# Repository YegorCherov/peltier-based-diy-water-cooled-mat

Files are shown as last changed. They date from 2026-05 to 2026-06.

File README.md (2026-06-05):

# Peltier Water Cooled Sleeping Mat

I bought a water cooled sleeping mat but the station it came with was evaporation based, extremely loud, and needed constant refilling. It also barely worked in hot and humid weather so I decided to build a proper replacement using a peltier module and a real water cooling setup.

It worked but the peltier could not keep up with the heat load so I scrapped it. Everything is documented here anyway because the build itself came out well and the failure is worth understanding.

## Parts

| Part | Details |
|---|---|
| Peltier module | TEC1 12706, 40x40mm, 12V |
| Water block | ARSYLID pure copper, 40x40x10mm |
| Pump | 280L/H brushless DC, 12V 5W, submersible |
| Power supply | 100W 12V switching PSU |
| Motor driver | BTS7960 43A H bridge |
| Buck converter | LM2596 or MP1584, 12V to 5V |
| Microcontroller | ESP32 |
| Coolant | 85% distilled water, 15% car coolant |
| Enclosure | 3D printed |

## Build

The core of the system is the peltier module sandwiched between a copper water block on the cold side and a heatsink with fan on the hot side.

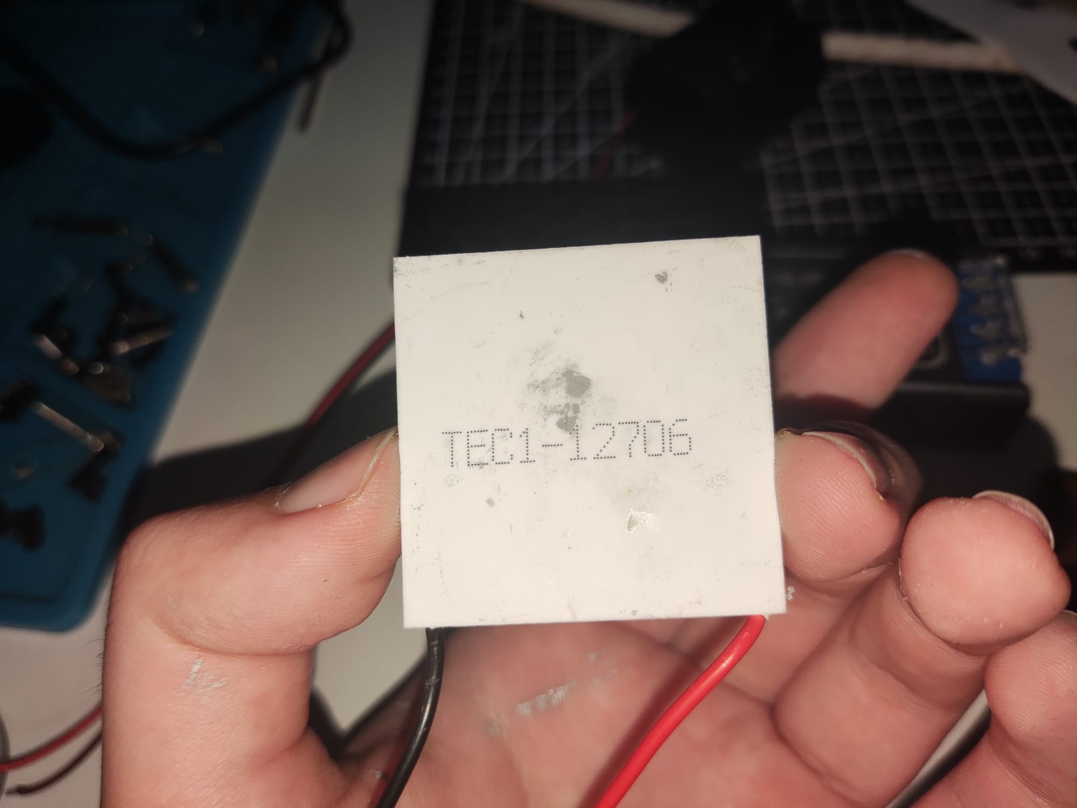
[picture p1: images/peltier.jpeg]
Peltier module


The water block sits against the cold face of the peltier and circulates coolant through the mat.

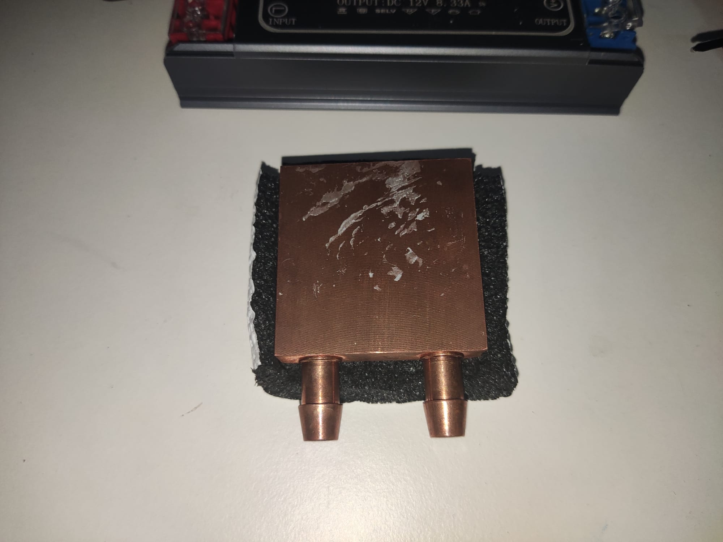
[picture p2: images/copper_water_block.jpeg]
Copper water block


The heatsink and fan go on the hot side to dump heat out of the peltier.

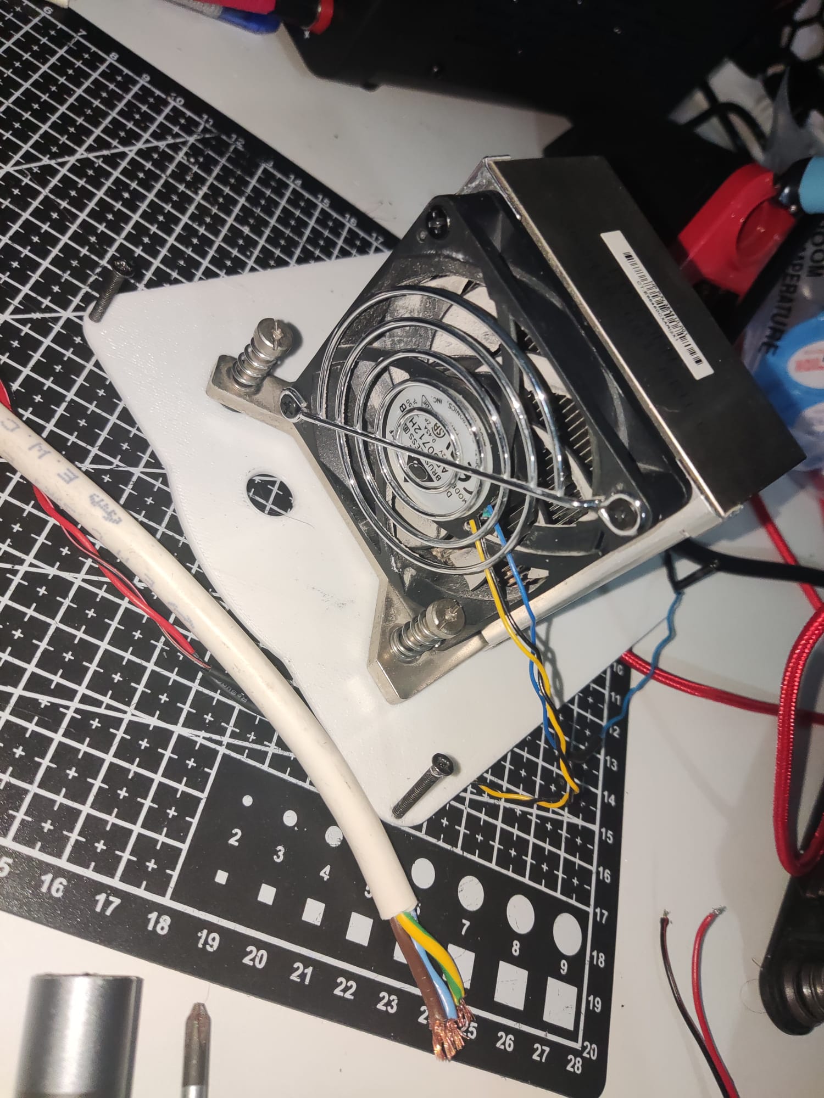
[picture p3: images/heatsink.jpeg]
Heatsink and fan


A brushless submersible pump circulates the coolant through the loop.

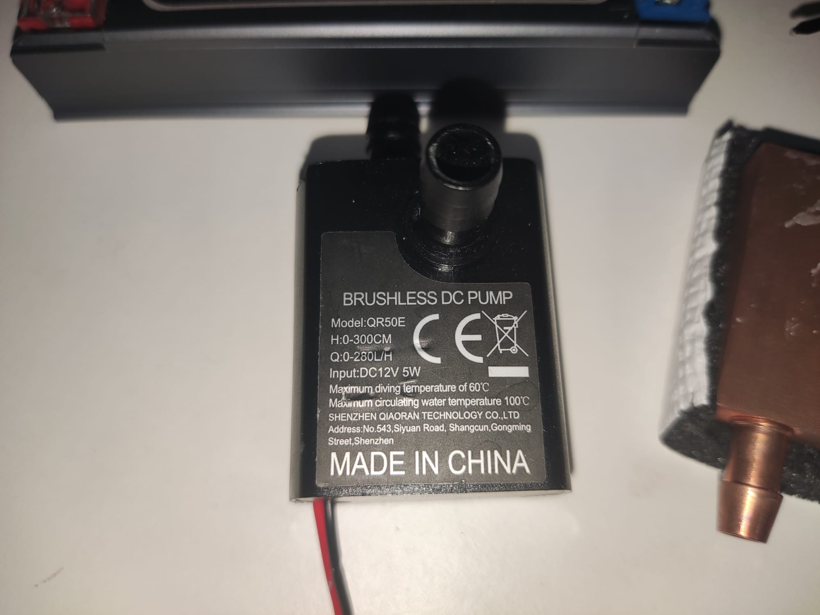
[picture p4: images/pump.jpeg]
Pump


The whole system runs off a 100W 12V switching PSU.

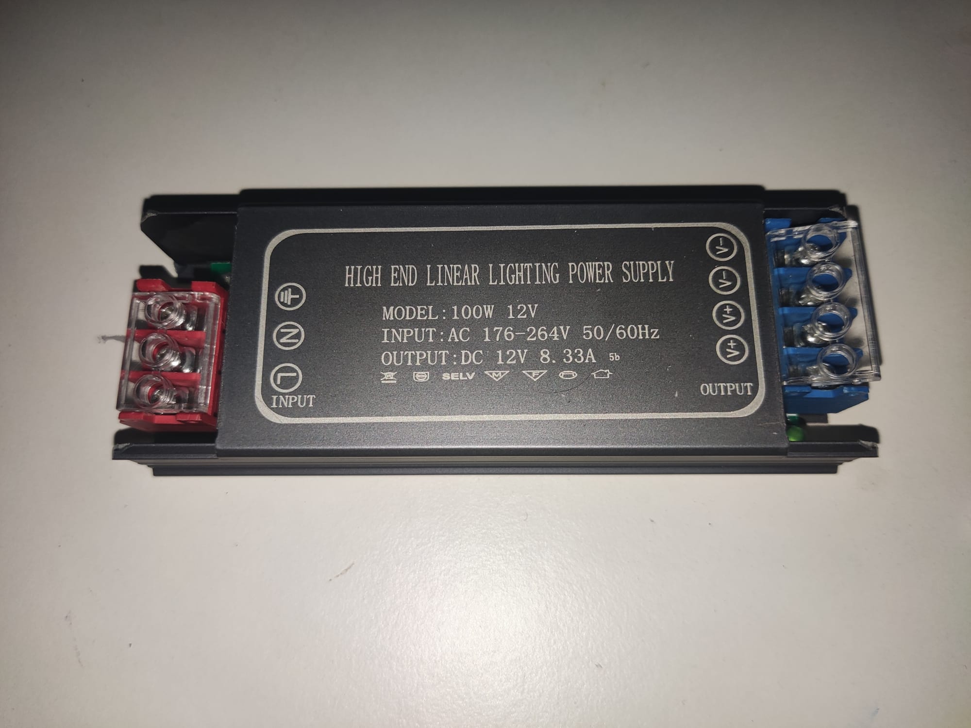
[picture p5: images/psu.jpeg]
PSU


An ESP32 handles control. It hosts a web UI over WiFi for adjusting fan speed, peltier power, and setting presets.

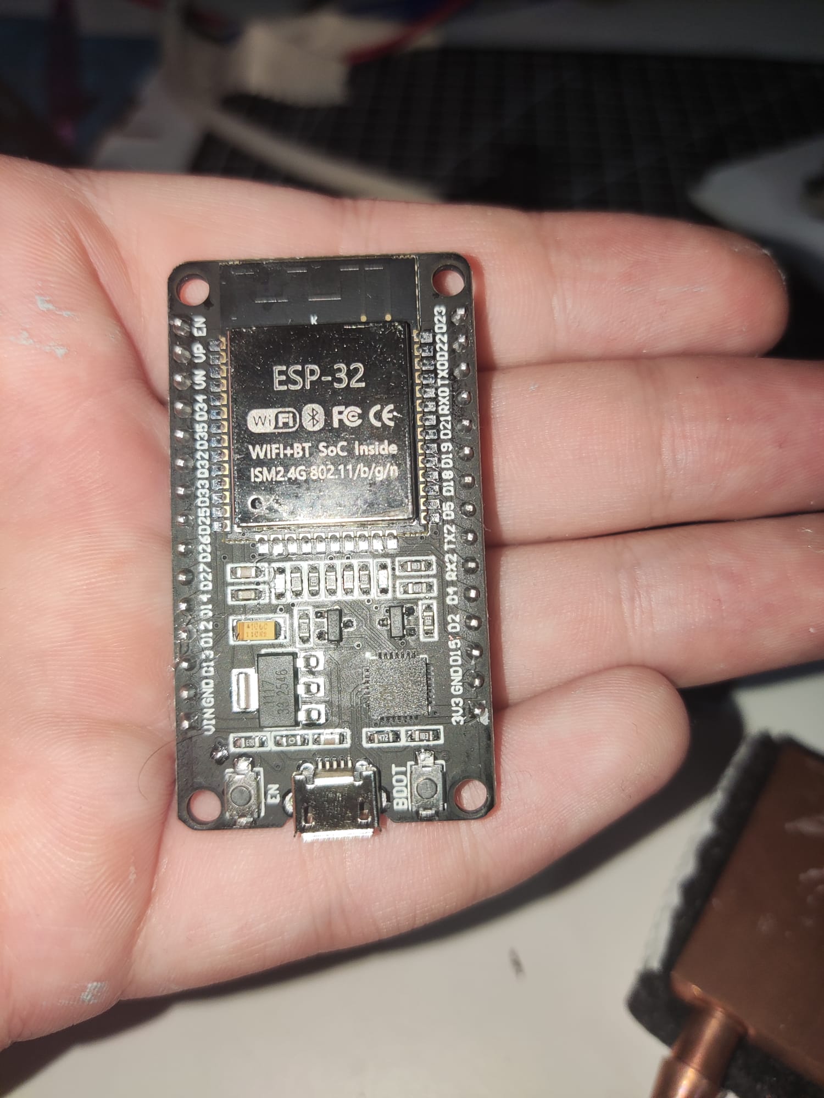
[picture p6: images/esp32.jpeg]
ESP32


The BTS7960 motor driver handles PWM control of the peltier. A buck converter steps 12V down to 5V to power the ESP32.

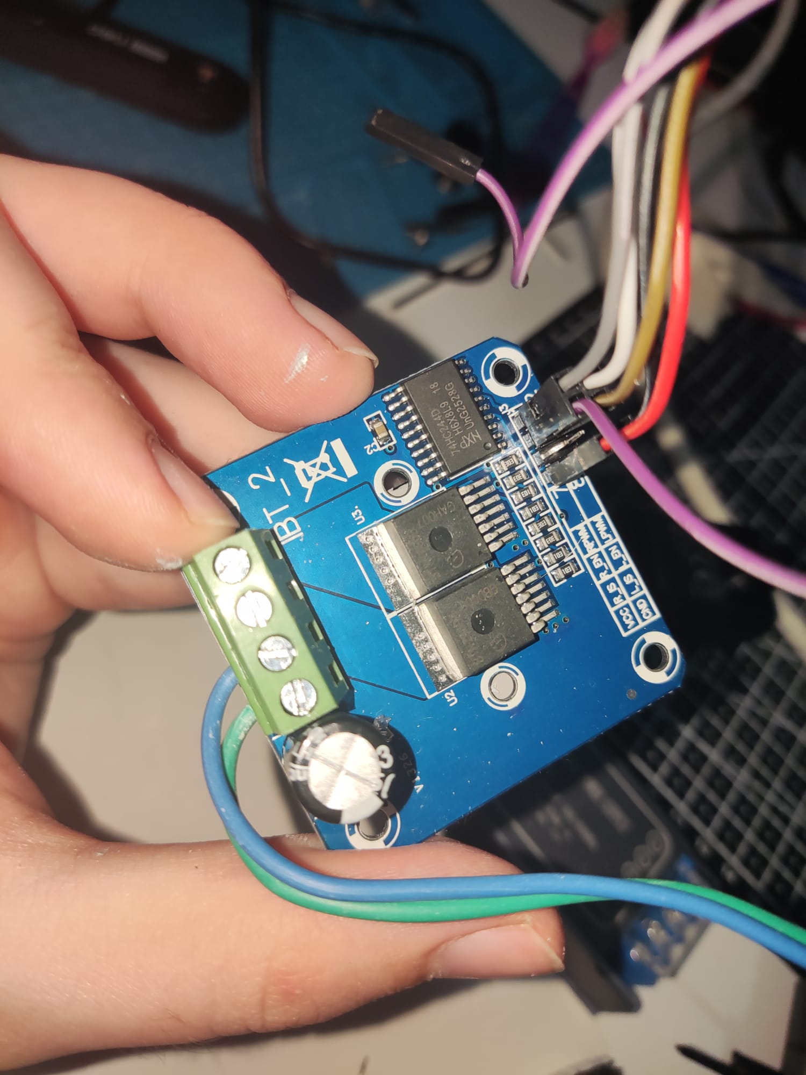
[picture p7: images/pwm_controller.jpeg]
BTS7960 PWM controller


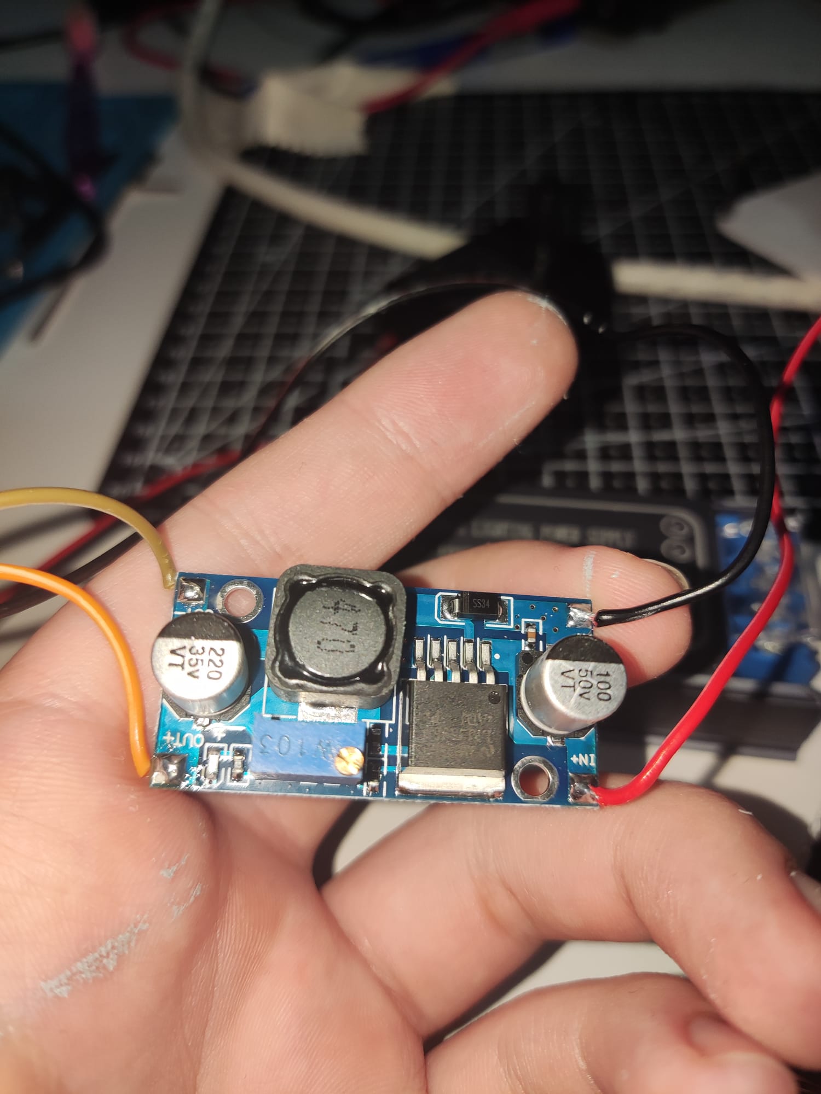
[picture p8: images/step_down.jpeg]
Buck converter


Everything sits inside a 3D printed enclosure. The water block was wrapped in a sleeve cut from AC cable casing to insulate it and prevent condensation on the outside.

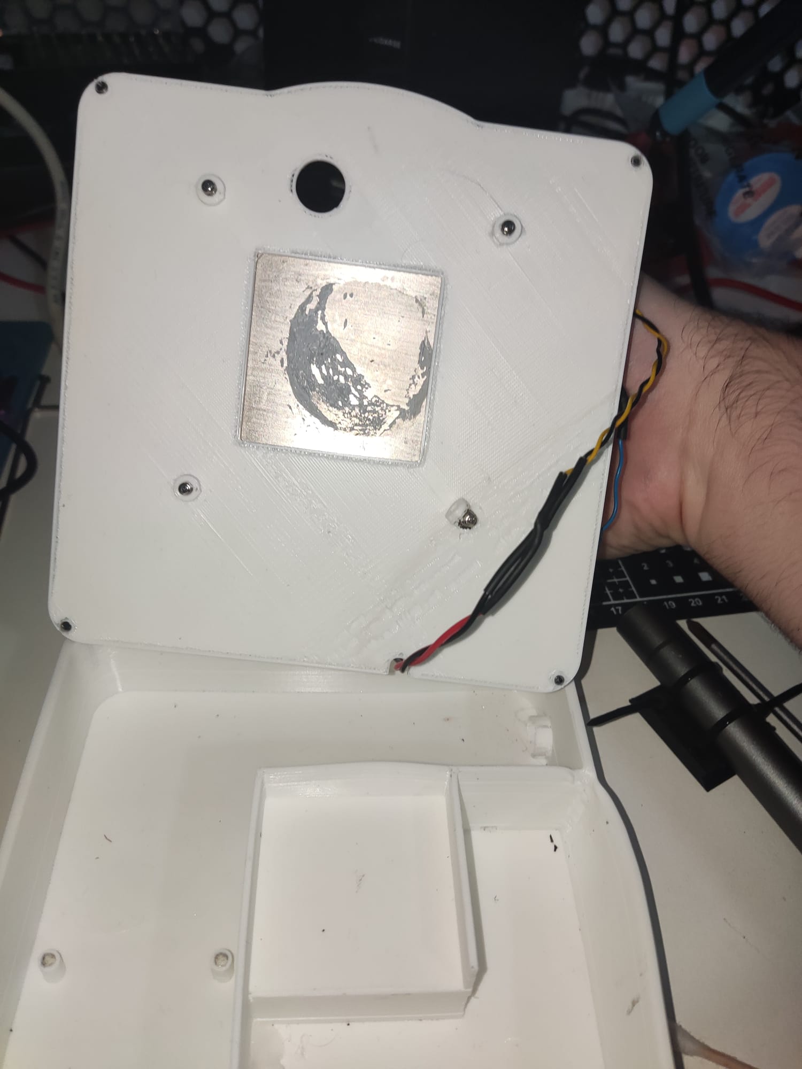
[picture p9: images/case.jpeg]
3D printed case


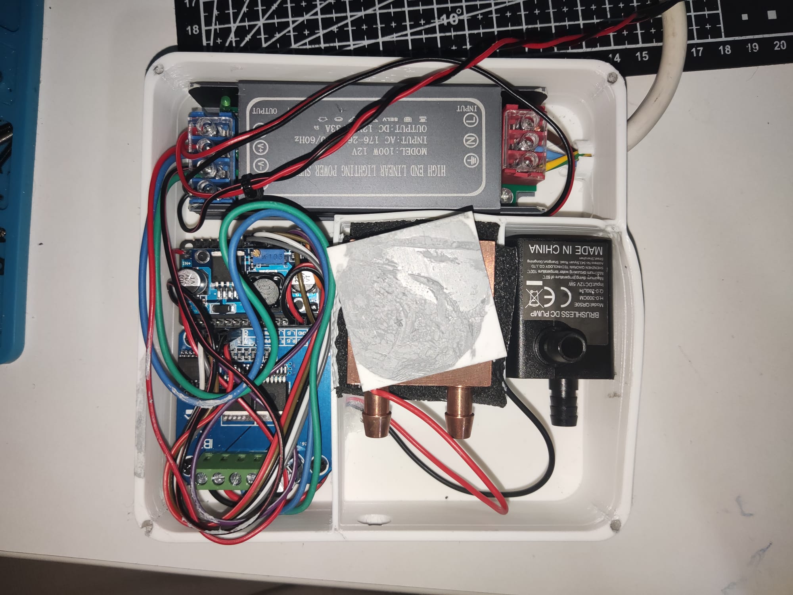
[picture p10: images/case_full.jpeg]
Full build inside case


The coolant is an 85/15 mix of distilled water and automotive glycol to prevent mineral deposits, corrosion and biological growth in the closed loop.

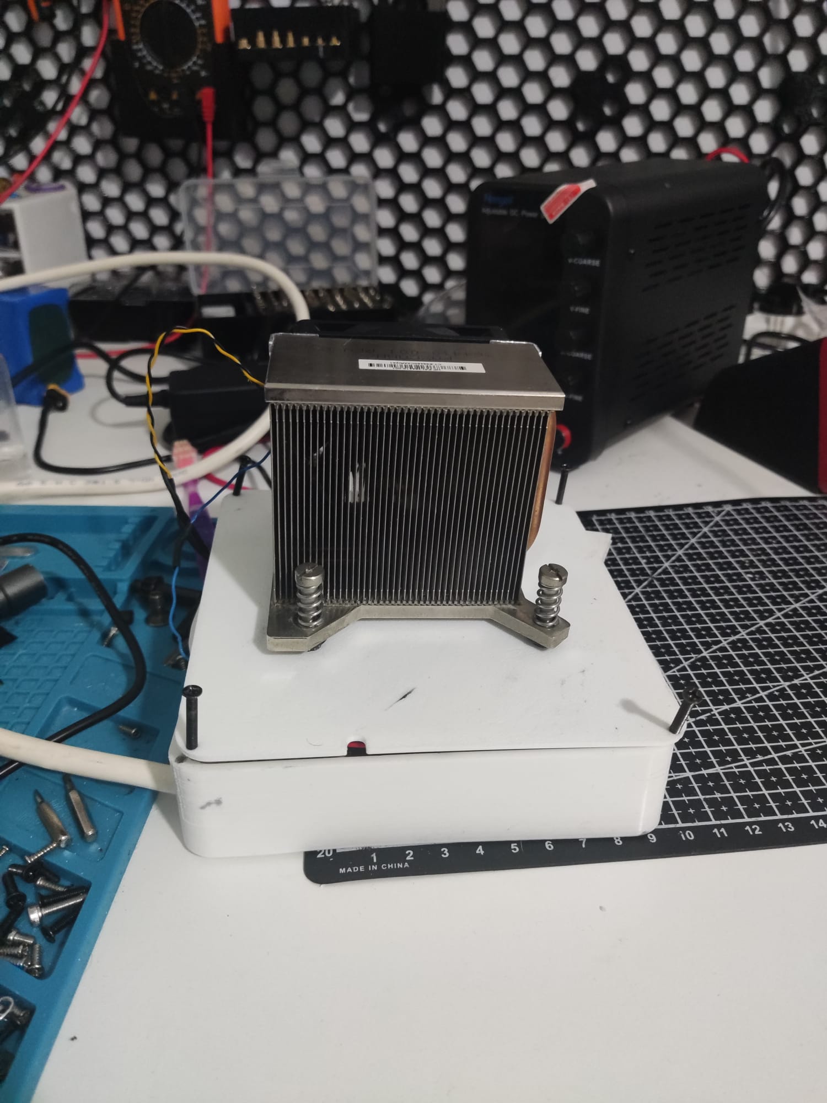
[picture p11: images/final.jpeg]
Full system


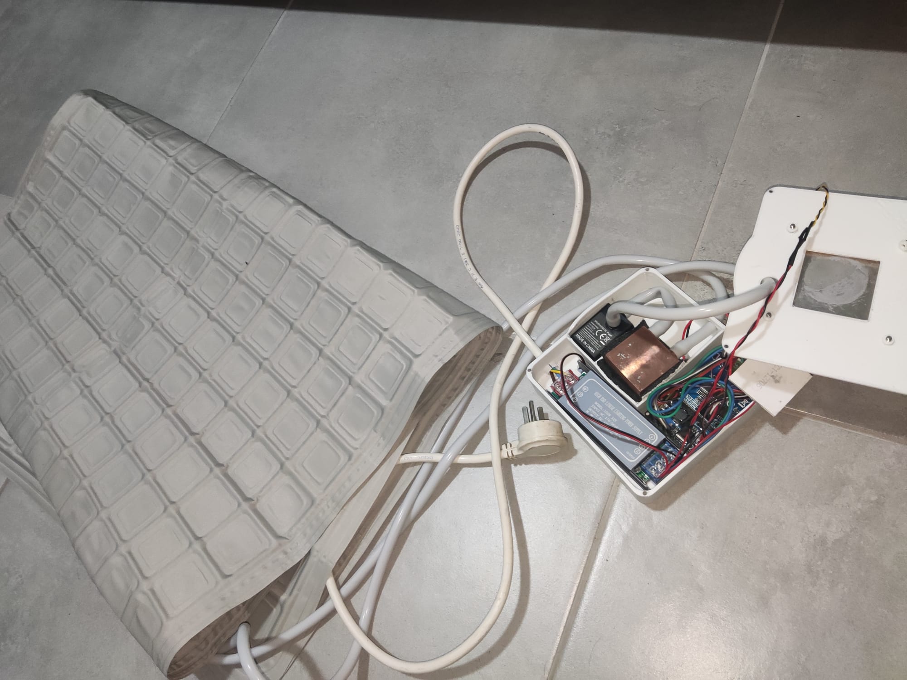
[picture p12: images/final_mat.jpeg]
Final setup


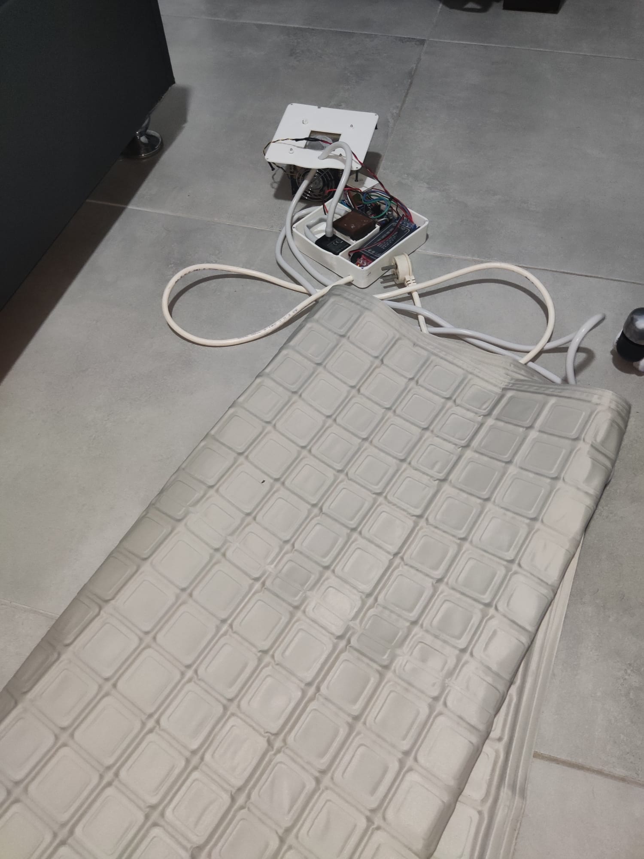
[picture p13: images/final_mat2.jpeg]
Final setup


## Wiring

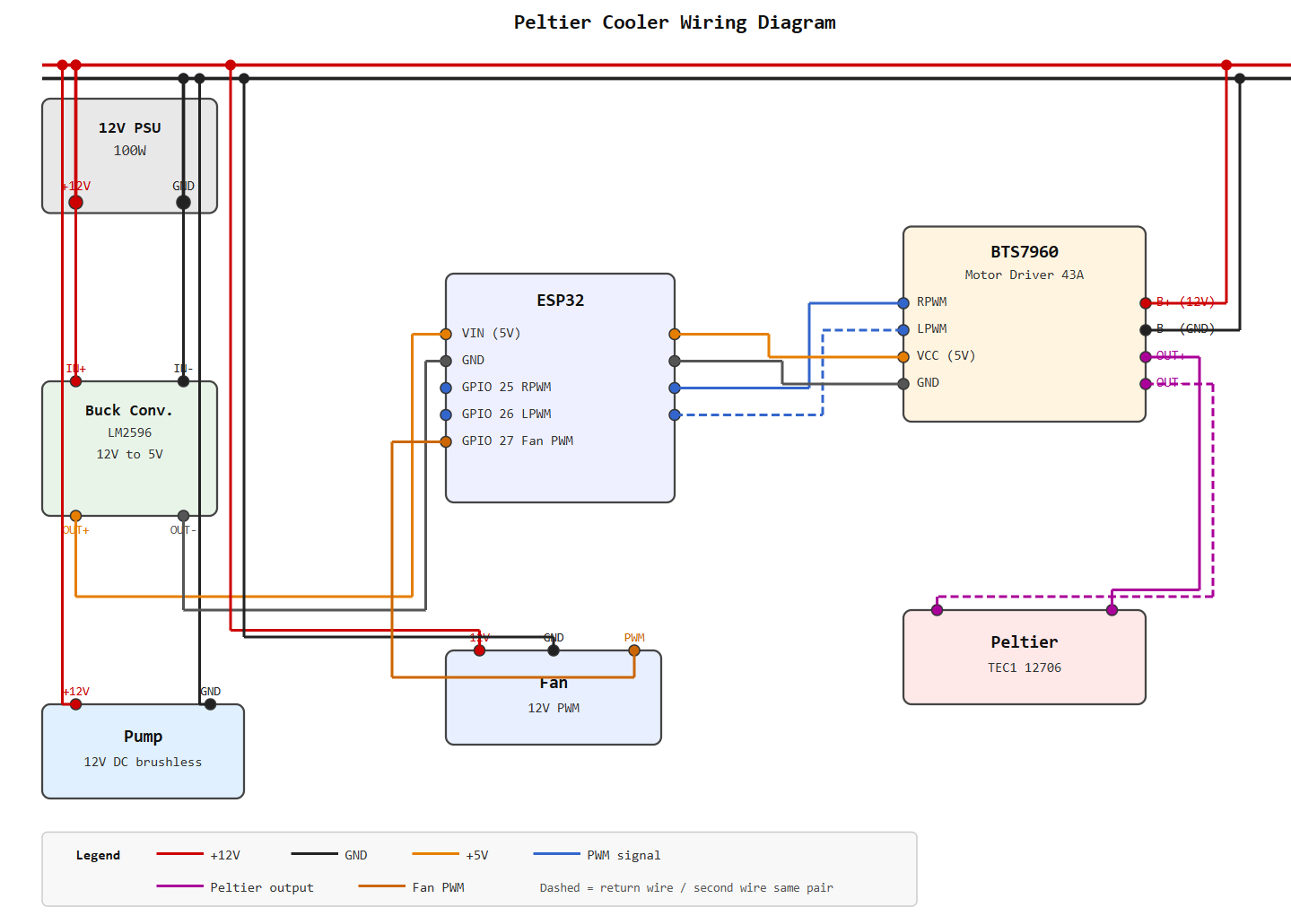
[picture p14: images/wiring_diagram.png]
Wiring diagram


12V PSU positive rail to BTS7960 power input and to buck converter input. PSU negative to shared ground. Buck converter output 5V to ESP32 VIN, ground to shared ground. BTS7960 RPWM and LPWM to ESP32 GPIO 25 and 26. Fan PWM to ESP32 GPIO 27. Water block on peltier cold side, heatsink and fan on hot side.

## Why It Failed

The TEC1 12706 has a decent temperature differential on paper but in practice it has to cool the water loop and reject that heat into the air at the same time. When ambient temperature is high the hot side heatsink gets warm fast, which compresses the usable temperature differential until the peltier is basically doing nothing useful. A single module of this class cannot cool a body contact mat in hot conditions. You would need stacked modules, a much larger cold reservoir, or a compressor based chiller.

## What Worked Fine

The pump was extremely quiet, no issues at all. The BTS7960 ran cool and gave smooth PWM control. The coolant loop had no leaks. The web UI worked well and the presets were convenient.

## Lessons Learned

A peltier module moves heat, it does not generate cold. The usable temperature differential shrinks as the hot side heats up, and in a hot environment the hot side heatsink cannot dump heat fast enough to keep up.

The fix would be stacking multiple peltier modules, using a much larger heatsink and fan on the hot side, or switching to a compressor based chiller entirely. A single TEC1 12706 is not enough for a body contact cooling load.

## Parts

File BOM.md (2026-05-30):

# Bill of Materials

| Part | Model | Source | Price (ILS) |
|---|---|---|---|
| Peltier module | TEC1 12706, 40x40mm, 12V | AliExpress | 5.85 |
| Water block | ARSYLID pure copper, 40x40x10mm | AliExpress | 33.09 |
| Pump | 280L/H brushless DC, 12V 5W, submersible | AliExpress | 12.98 |
| Power supply | 100W 12V switching PSU | AliExpress | 10.60 |
| Motor driver | BTS7960 43A H bridge | AliExpress | 12.38 |
| Temp sensor | DS18B20 waterproof, 1m cable | AliExpress | 4.07 |

**Total: ₪78.97**

Buck converter, ESP32, coolant, distilled water and 3D print filament
not included as these were sourced separately or already on hand.

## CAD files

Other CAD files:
cad/Water cooled mat cooling station.f3d
